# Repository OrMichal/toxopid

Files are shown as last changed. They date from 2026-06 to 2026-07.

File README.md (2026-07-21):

# Toxopid

>Octapod robot controlled via companion application.

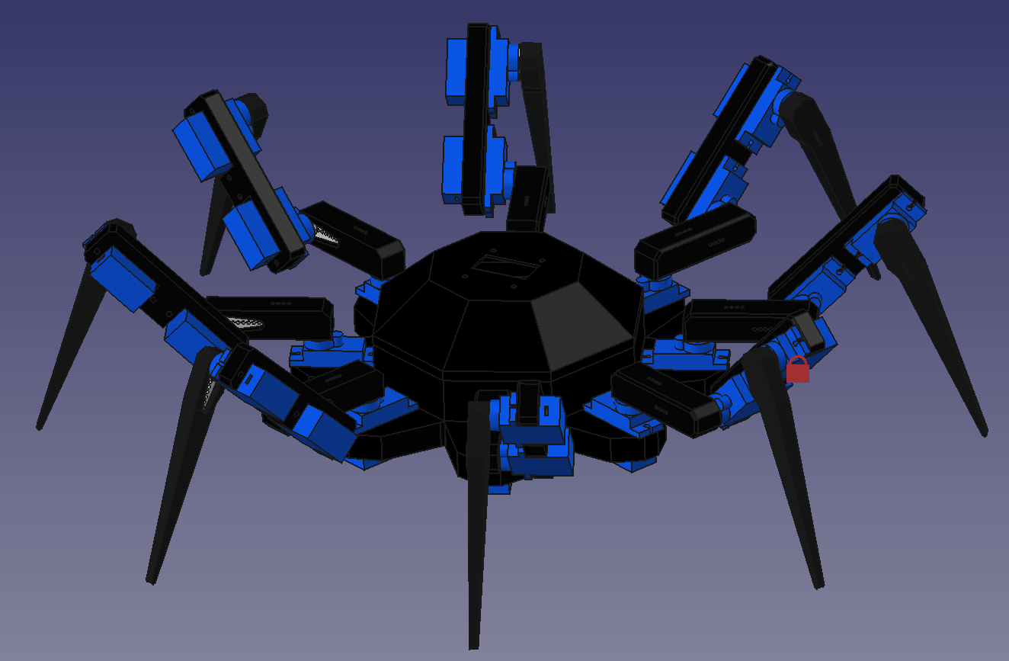
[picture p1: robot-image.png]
robot-image


---

# Components

1) MCU - [RaspberryPi pico 2 wh](https://www.gme.cz/v/1517388/raspberry-pico-2-wh)
2) Servo (24) - [MG90S](https://dratek.cz/arduino-platforma/180244-servomotor-sg90-360-kontinualni.html)
3) Display - [OLED displej 0,96"](https://www.gme.cz/v/1509095/oled-displej-096-128x64-i2c-bily)
4) Servo module [24-channel](https://www.gme.cz/v/1508859/modul-24-kanalovy-budic-servo-motoru)
5) Battery [GNB 1100mAh 2S](https://www.rotorama.cz/product/gnb-1100mah-2s-60c-hv)
6) Step-down convertor (2) [XL4005](https://www.laskakit.cz/step-down-menic-s-xl4005/)
7) Battery management module [INA226](https://www.laskakit.cz/en/laskakit-ina226-sensor-pro-mereni-napeti--proudu-a-vykonu/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)

---

# Physical attributes

## Legs

>Each leg consists of 3 parts: Coxa, Femur and Tibia

$$
Coxa \approx 5,81 cm^3
$$

$$
Femur \approx 4,75cm^3
$$

$$
Tibia \approx 3,44cm^3
$$

>From this I calculated weight for each leg.

$$
Leg = (Coxa + Femur + Tibia) \cdot MaterialDensity + 3 \cdot Servo
$$

>Servo motors used weight $13g$ and I used `PLA` as my material for parts that means:

$$
Leg \approx 57,2g
$$

$$
AllLegs \approx 457,5g
$$

Leg lengths:

| Coxa  | 5cm  |
| ----- | ---- |
| Femur | 8cm  |
| Tibia | 11cm |

---

## Electronic components

>Weight of each electrical component used.

$$
Battery \approx 46g
$$

$$
StepDownConvertor \approx 66g
$$

$$
ServoModule \approx 60g
$$

$$
MCU = 6g
$$

$$
Display = 3g
$$

>Electrical components (without servos) weight around: $247g$.

---

## Summary of Physical attributes

$$
LowerTorso \approx 157g
$$

$$RoofTorso \approx 22,5g$$

$$Leg \approx 8 \cdot 58g$$

$$
ElectricalParts \approx 247g
$$

---

$$
\text{Weight of the model} \approx 321,75g
$$

$$
\text{Total weight} \approx 881g
$$

---

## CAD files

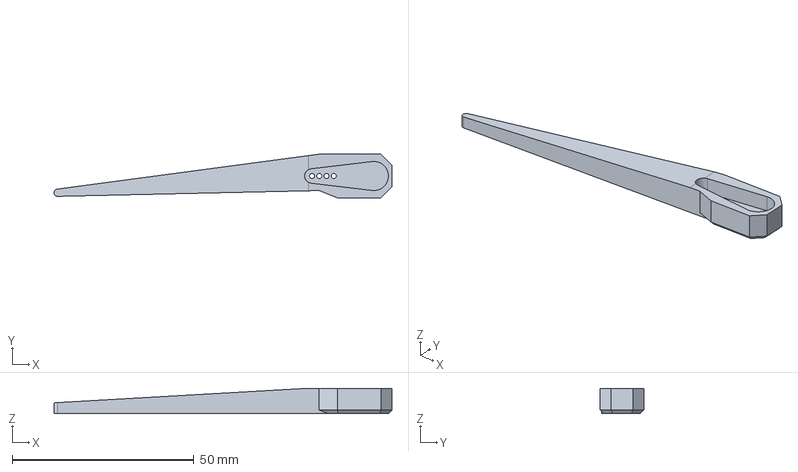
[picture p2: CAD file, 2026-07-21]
3d-model/components/Tibia.FCStd
92.9 x 12.0 x 7.00 mm

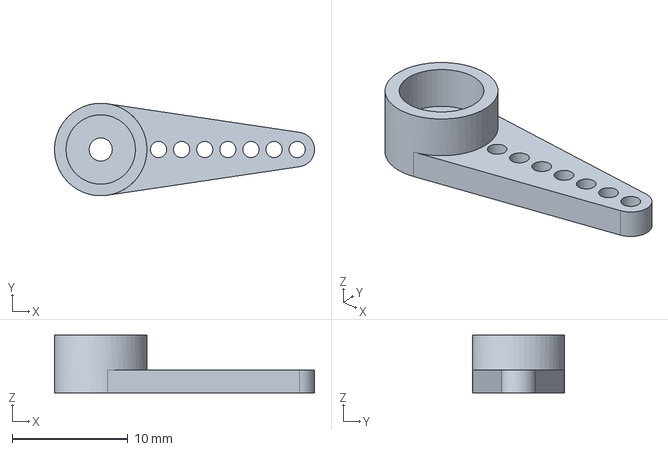
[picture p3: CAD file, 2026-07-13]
3d-model/imports/SG90-1-arm-horn.fcstd
22.5 x 8.00 x 5.00 mm

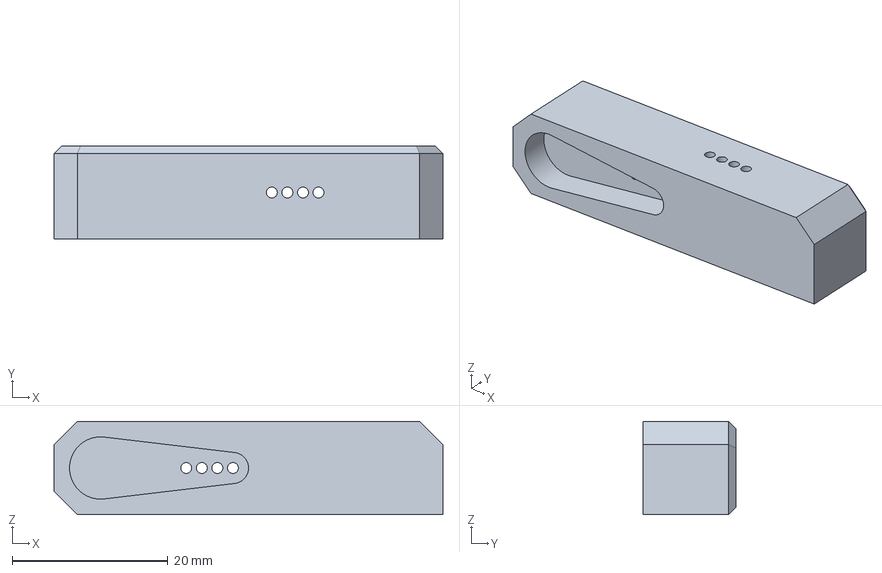
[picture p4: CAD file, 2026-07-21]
3d-model/Mesh/Coxa.3mf
50.0 x 12.0 x 12.0 mm

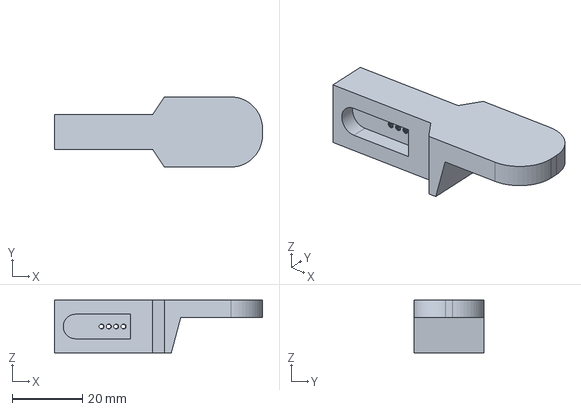
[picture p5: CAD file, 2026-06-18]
3d-model/claw_bottom.FCStd
59.3 x 20.0 x 15.0 mm

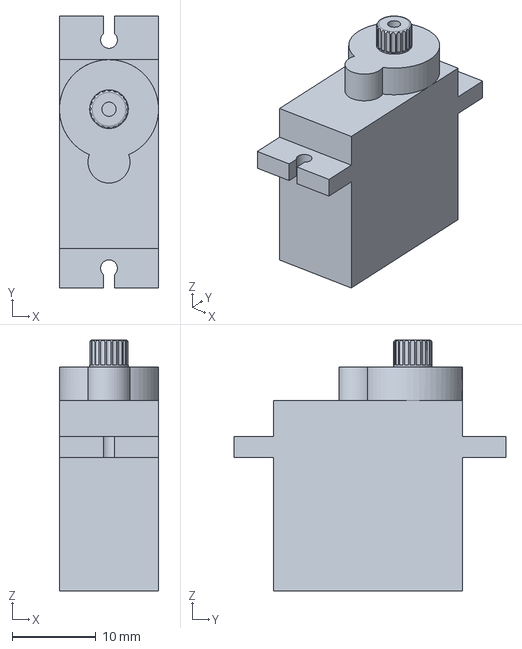
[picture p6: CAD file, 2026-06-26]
3d-model/imports/Servo sg90.fcstd
11.8 x 32.4 x 29.9 mm

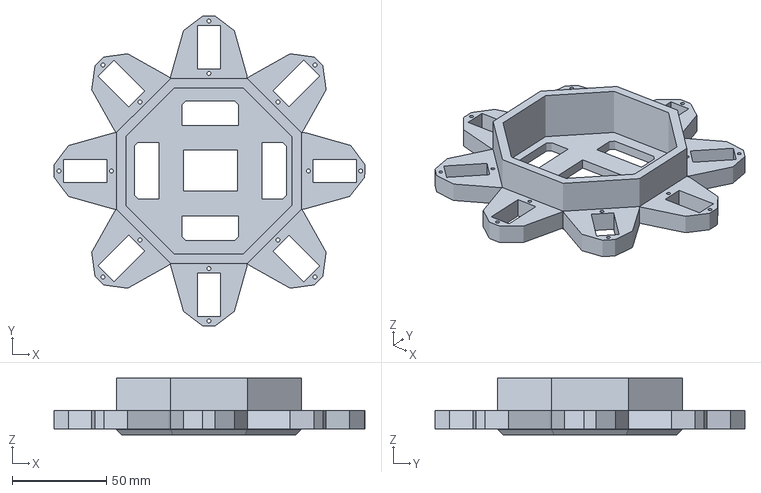
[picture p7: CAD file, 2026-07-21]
3d-model/Mesh/Torso-lower.3mf
164.6 x 164.0 x 30.0 mm

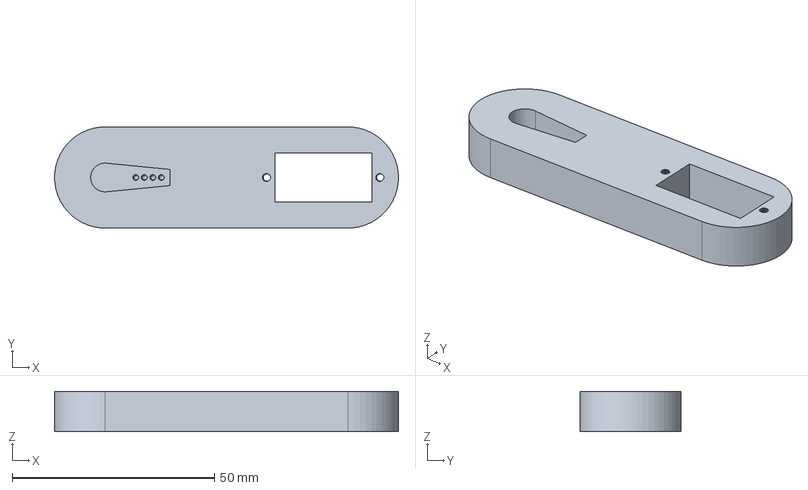
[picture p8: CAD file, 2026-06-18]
3d-model/claw_middle.FCStd
85.0 x 25.0 x 10.0 mm

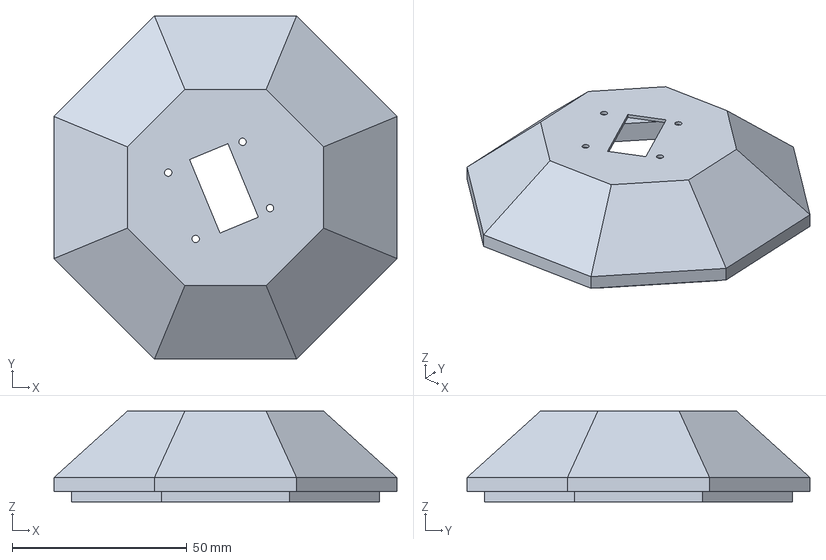
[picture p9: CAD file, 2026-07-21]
3d-model/components/Torso-roof.FCStd
98.0 x 98.0 x 26.0 mm

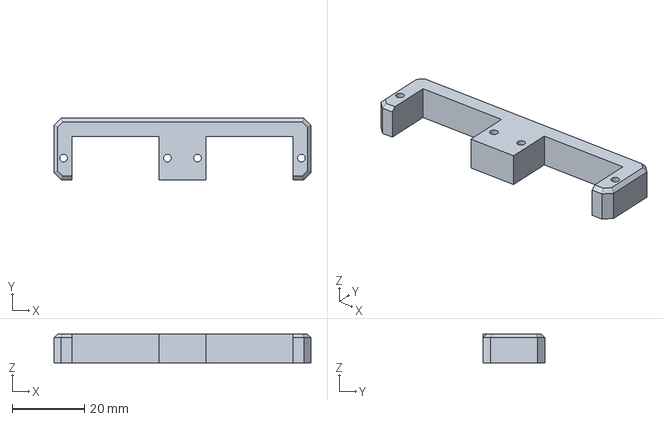
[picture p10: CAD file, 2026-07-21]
3d-model/Mesh/Femur.3mf
71.0 x 17.0 x 8.00 mm

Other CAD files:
3d-model/assemblies/Claw.FCStd
3d-model/Model-variables.FCStd
3d-model/assemblies/Final.FCStd
3d-model/components/Coxa.FCStd
3d-model/Mesh/Torso-roof.3mf
3d-model/components/Torso-lower.FCStd
3d-model/components/Femur.FCStd
3d-model/Mesh/Tibia.3mf

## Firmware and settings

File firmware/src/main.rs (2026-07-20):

#![no_std]
#![no_main]

mod robot;

use defmt::*;
use defmt_rtt as _;
use embedded_graphics::Drawable;
use embedded_graphics::geometry::Point;
use embedded_graphics::mono_font::MonoTextStyleBuilder;
use embedded_graphics::mono_font::ascii::FONT_6X10;
use embedded_graphics::pixelcolor::BinaryColor;
use embedded_graphics::text::Text;
use embedded_hal::digital::OutputPin;
use hal::fugit::RateExtU32;
use hal::uart::DataBits;
use hal::uart::StopBits;
use heapless::format;
use panic_probe as _;
use rp235x_hal::binary_info::DataType::BinaryInfoListZeroTerminated;
use rp235x_hal::clocks::init_clocks_and_plls;
use rp235x_hal::fugit::HertzU32;
use rp235x_hal::gpio::FunctionI2c;
use rp235x_hal::gpio::Pin;
use rp235x_hal::gpio::PullUp;
use rp235x_hal::uart::{UartConfig, UartPeripheral};
use rp235x_hal::{self as hal, entry};
use rp235x_hal::{Clock, pac};
use ssd1306::I2CDisplayInterface;
use ssd1306::Ssd1306;
use ssd1306::mode::DisplayConfig;
use ssd1306::rotation::DisplayRotation;
use ssd1306::size::DisplaySize128x64;

use crate::robot::expressions::Expression;
use crate::robot::tox::Tox;

#[unsafe(link_section = ".start_block")]
#[used]
pub static IMAGE_DEF: hal::block::ImageDef = hal::block::ImageDef::secure_exe();

#[entry]
fn main() -> ! {
    let mut pac = pac::Peripherals::take().unwrap();
    let mut watchdog = hal::Watchdog::new(pac.WATCHDOG);
    let sio = hal::Sio::new(pac.SIO);

    let clocks = init_clocks_and_plls(
        12_000_000,
        pac.XOSC,
        pac.CLOCKS,
        pac.PLL_SYS,
        pac.PLL_USB,
        &mut pac.RESETS,
        &mut watchdog,
    )
    .ok()
    .unwrap();

    let pins = hal::gpio::Pins::new(
        pac.IO_BANK0,
        pac.PADS_BANK0,
        sio.gpio_bank0,
        &mut pac.RESETS,
    );

    let sda_pin = pins.gpio18.into_function::<FunctionI2c>().into_pull_type();
    let scl_pin = pins.gpio19.into_function::<FunctionI2c>().into_pull_type();

    let i2c = hal::I2C::i2c1(
        pac.I2C1,
        sda_pin,
        scl_pin,
        400.kHz(),
        &mut pac.RESETS,
        &clocks.system_clock,
    );

    let interface = I2CDisplayInterface::new(i2c);
    let mut display = Ssd1306::new(interface, DisplaySize128x64, DisplayRotation::Rotate0)
        .into_buffered_graphics_mode();

    display.init().unwrap();

    let mut tox = Tox::new(display);
    tox.set_expression(Expression::Idle);

    loop {
        tox.update_display();

        cortex_m::asm::wfi();
    }
}

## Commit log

2026-06-09 started working on a 3d model
    [claw_lower.FCStd]
2026-06-14 lower claw done
    [claw_lower.FCStd, claw_middle.FCStd]
2026-06-14 middle claw done
    [claw_middle.FCStd]
2026-06-18 servo rotation works
    [claw_bottom.FCStd, claw_lower.FCStd, claw_middle.FCStd]
2026-06-18 3D model of legs almost done
    [claw_lower.FCStd]
2026-06-20 3D model of a lower torso is done and I am starting to work on the rest of the torso. Also claw design needs to be remade so it looks better
    [Torso_lower.FCStd, claw_lower.FCStd]
2026-06-23 3D model is almost done. I only need one more middle floor for the battery & step-down motors.
    [Final.FCStd, Torso_lower.FCStd, Torso_middle_floor.FCStd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]
2026-06-26 3D model of claws is a lot better, but it won't be a small robot lmao.
    [Claw-assembly.FCStd, Final.FCStd, SG90-1-arm-horn.fcstd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]
2026-07-03 3D model done, but I need to start optimizing it for printing so it won't be too heavy
    [Assembly-variables.FCStd, Claw-assembly.FCStd, Final.FCStd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]
2026-07-13 Refactored 3D model and now should be ready for printing.
    [Assembly-variables.FCStd, Claw-assembly.FCStd, Claw.FCStd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]
2026-07-20 redesigned Torso-roof and correctly calculated its volume
    [Claw.FCStd, Coxa.FCStd, Coxa.stl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]
2026-07-21 shortened Tibia limb and generated .3mf mesh
    [Claw.FCStd, Coxa.3mf, Coxa.FCStd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]
